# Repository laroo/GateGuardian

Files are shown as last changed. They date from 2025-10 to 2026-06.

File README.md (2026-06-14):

# Gate Guardian



  

**Automating the Sommer Twist 350 Swing Gate with ESP32 and MQTT**

This repository contains the design and code for Gate Guardian, an ESP32 swing gate controller designed to operate and monitor a Sommer Twist 350 swing gate. The system integrates remote control via MQTT over Ethernet, real-time status monitoring, and visual feedback. The design emphasizes reliability, safety, and ease of installation.

## Changelog

v1.1
- Changed pins for status LEDs as these were input only:
  - Red LED: GPIO 17 (from GPIO 39)
  - Green LED: GPIO 5 (from GPIO 36)
  - Photo eye: GPIO 36 (from GPIO 5)

v1.0
- Initial release

## MQTT Configuration

### MQTT Topics

```
gateguardian/state = CLOSED
gateguardian/sensor/lock = 0
gateguardian/sensor/lights = 0
gateguardian/sensor/photo_eye = 0
gateguardian/sensor/external_relay = 0
gateguardian/client_id = esp32_gate_FFAA00
gateguardian/uptime = 1510
gateguardian/in_motion = 0
```

### MQTT Commands

```
gateguardian/command = OPEN
gateguardian/command = CLOSE
gateguardian/command = STOP
```

## Home Assistant Configuration

The Home Assistant configuration can be found [here](home-assistant/configuration.yaml).

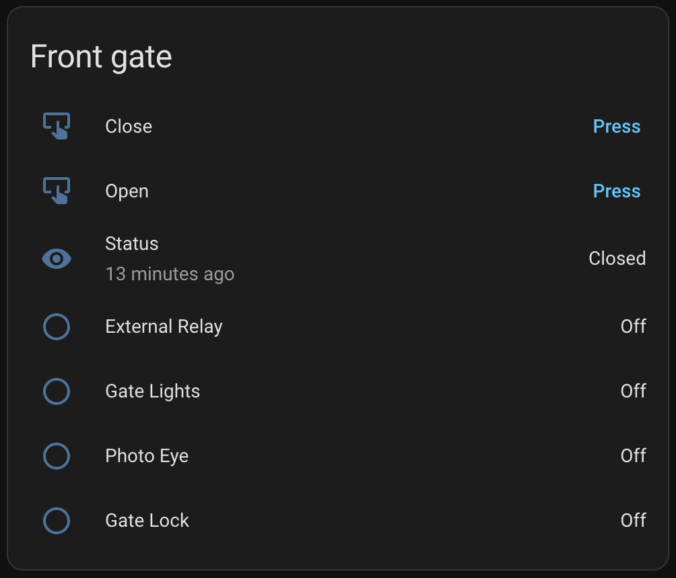
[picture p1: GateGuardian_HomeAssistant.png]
GateGuardian_HomeAssistant


## Schematics and PCB

Used LibrePCB to design the schematics and PCB.

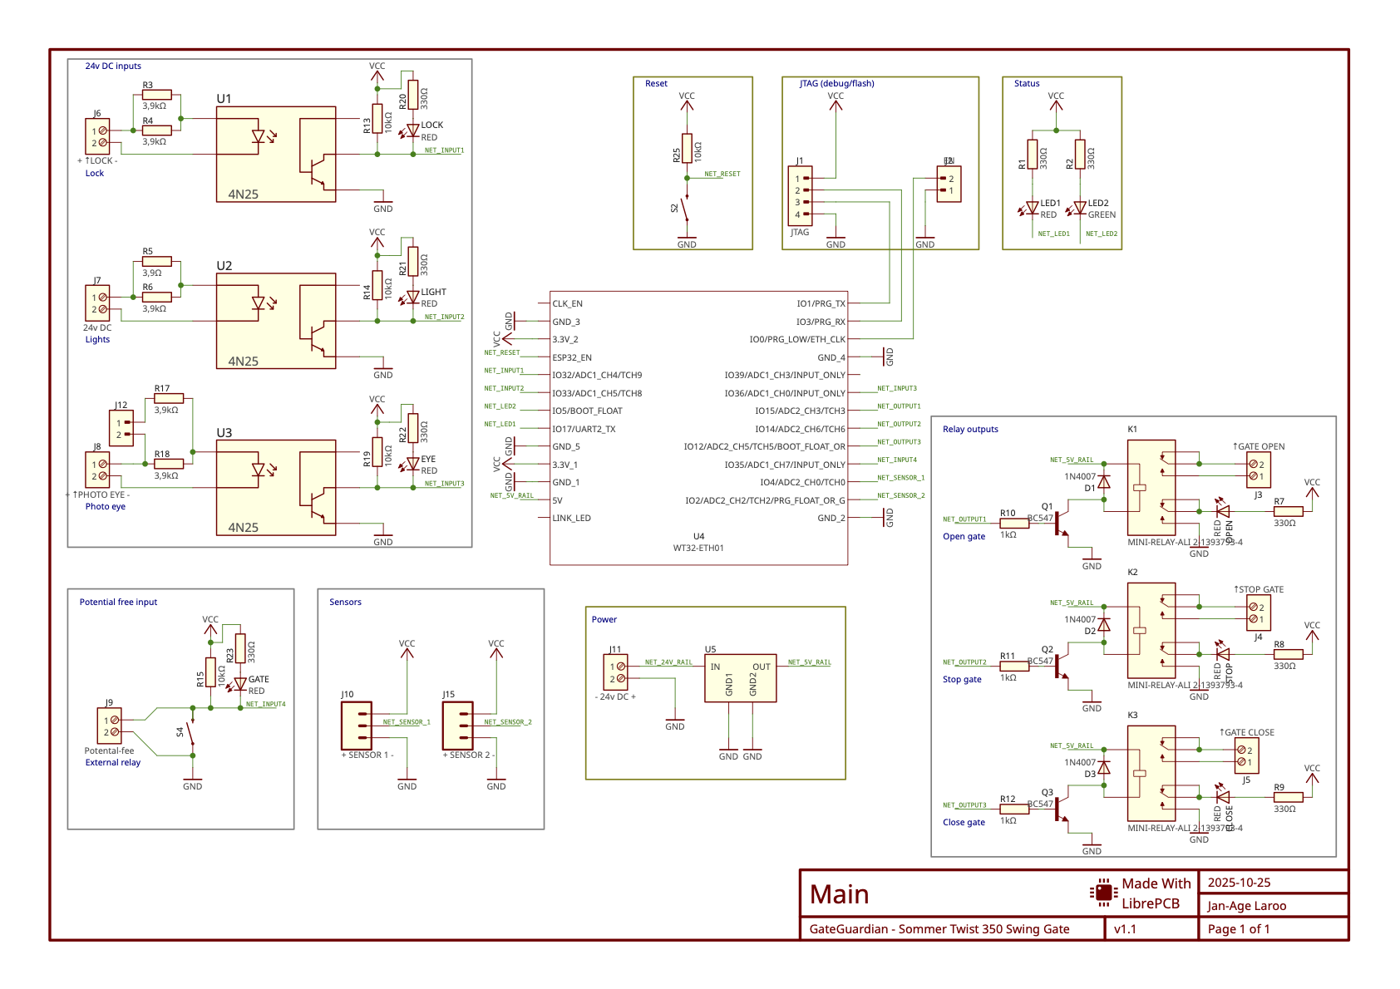
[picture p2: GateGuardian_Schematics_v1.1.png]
Schematic


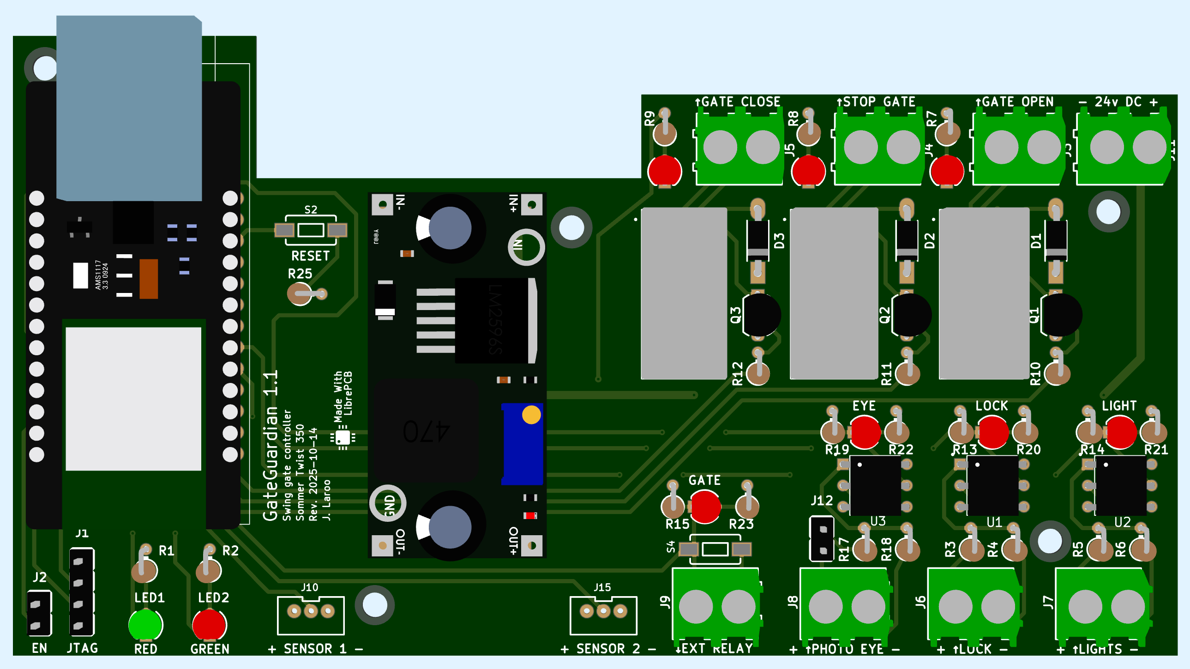
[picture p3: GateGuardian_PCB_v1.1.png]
PCB


Gerber files for the PCB can be found [here](librepcb/output/v1.1/gerber).

# Input/Output

| Pin | Direction | Function | Note |
|----|---|---|---|
| GPIO 12 | Output | Gate Close Relay | Pulse to close the gate |
| GPIO 14 | Output | Gate Stop Relay | Pulse to stop the gate |
| GPIO 15 | Output | Gate Open Relay | Pulse to open the gate |
| GPIO 17 | Output | Red LED | Blinking during closing, solid during opening |
| GPIO 5 | Output | Green LED | Blinking during opening, solid during closing |
| GPIO 33 | Input | Gate Lights | Blinking warning light when opening or cloing |
| GPIO 32 | Input | Gate Lock | Enabled when gate is closed |
| GPIO 35 | Input | External Relay | Triggered when gate is closed |
| GPIO 36 | Input | Photo eye | When someone/omething goes through the gate |
| GPIO 4 | Input | Sensor 1 | Optional sensor (dht22 temperature sensor) |
| GPIO 2 | Input | Sensor 2 | Optional sensor (not used) |

## Code

The firmware is built on the Arduino framework using PlatformIO and implements a robust gate control system with the following key features:

- **MQTT Integration**: Remote control and status monitoring via MQTT over Ethernet (W5500)
- **Visual Feedback**: Dual LED system (red/green) indicating gate state with blinking patterns during movement
- **Position Sensing**: Real-time gate position detection using magnetic sensors
- **Safety Features**: Relay pulse timing, state machine logic, and operation timeouts
- **Diagnostics**: Serial output at 115200 baud for debugging and monitoring

### Platform IO Setup

```
pyenv local 3.13
python -m venv .venv
source .venv/bin/activate
pip install -r requirements.txt
```

### Build

```
pio run
```

### Test

```
pio test -v -e native
```

Run a single test:

```
TEST_FILTER=test_open_cycle pio test -v -e native
```

### Upload (Serial)

```
pio run --target upload -v
```

### OTA (Over-the-Air) Update

The firmware includes [ElegantOTA](https://github.com/ayushsharma82/ElegantOTA) for wireless firmware updates over the network.

1. Open a browser and navigate to `http://<device-ip>/update`
2. Authenticate with the configured `OTA_USERNAME` and `OTA_PASSWORD`
3. Select the firmware binary (`.pio/build/esp32/firmware.bin`) and upload

OTA credentials are set as compile-time build flags in `private_config.ini`:

```ini
'-D OTA_USERNAME=youruser'
'-D OTA_PASSWORD=yourpassword'
```

### Web Interface

The device runs an HTTP server on port 80 with the following endpoints:

| Endpoint | Description |
|---|---|
| `/` | Device identification |
| `/gate/open` | Command gate to open |
| `/gate/close` | Command gate to close |
| `/gate/stop` | Command gate to stop |
| `/update` | ElegantOTA firmware update page |

### MQTT Sequence Recording

To capture live gate behaviour as a test sequence, enable recording in `private_config.ini`:

```ini
-D MQTT_SEQUENCE_RECORD
```

Then subscribe to the recording topic:

```sh
mosquitto_sub -h <broker> -p <port> -u <username> -P <password> -t gateguardian/sequence
```

Each received line is a CSV row ready to paste into a new `test/sequences/*.csv` file. Prepend the header:

```
timestamp_ms,sensorLock,sensorLights,sensorPhotoEye,sensorExternalRelay,expectedState
```

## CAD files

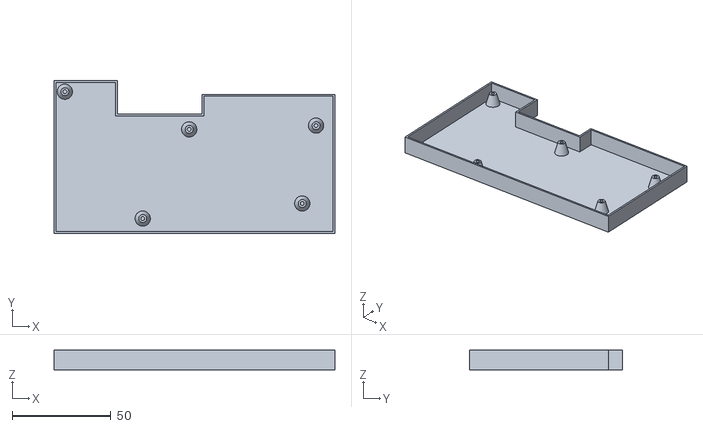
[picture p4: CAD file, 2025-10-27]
enclosure/gateguardian_box.stl
142.1 x 77.2 x 10.0

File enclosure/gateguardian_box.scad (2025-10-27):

// Import and extrude the GateGuardian box SVG
// Creates a 1mm thick wall with 10mm height and 0.5mm floor

$fn = 100;

// Define drill hole parameters
drill_radius = 4;
top_radius = 2;
drill_height = 7;
svg_height = 77209.998;
cutout_diameter = 2;
cutout_depth = 5;
box_height = 10;

// Define drill hole positions
drill_positions = [
    [(5799.4961 - 300) / 1000, (svg_height - (5880.9316 - 300)) / 1000],
    [(45168.711 - 300) / 1000, (svg_height - (70018.875 - 300)) / 1000],
    [(68659.102 - 300) / 1000, (svg_height - (24936.012 - 300)) / 1000],
    [(132804.52 - 300) / 1000, (svg_height - (23039.188 - 300)) / 1000],
    [(125817.86 - 300) / 1000, (svg_height - (62406.035 - 300)) / 1000]
];

difference() {
    union() {
        // Floor - 0.5mm thick
        linear_extrude(height = 0.5) {
            import("GateGuardian_box_only.svg");
        }
        
        // Walls - 1mm thick, 10mm height (starting from floor top)
        translate([0, 0, 0.5])
            linear_extrude(height = 9.5) {
                difference() {
                    import("GateGuardian_box_only.svg");
                    offset(delta = -1) {
                        import("GateGuardian_box_only.svg");
                    }
                }
            }
        
        // Drill holes - 5 conical cylinders
        translate([0, -0.6, 0]) {
            for (pos = drill_positions) {
                translate([pos[0], pos[1], 0])
                    cylinder(h = drill_height, r1 = drill_radius, r2 = top_radius);
            }
        }
    }
    
    // Cut out 2mm diameter cylinders, 5mm deep from the top
    translate([0, -0.6, 0]) {
        for (pos = drill_positions) {
            translate([pos[0], pos[1], box_height - cutout_depth])
                cylinder(h = cutout_depth + 0.1, r = cutout_diameter / 2);
        }
    }
}

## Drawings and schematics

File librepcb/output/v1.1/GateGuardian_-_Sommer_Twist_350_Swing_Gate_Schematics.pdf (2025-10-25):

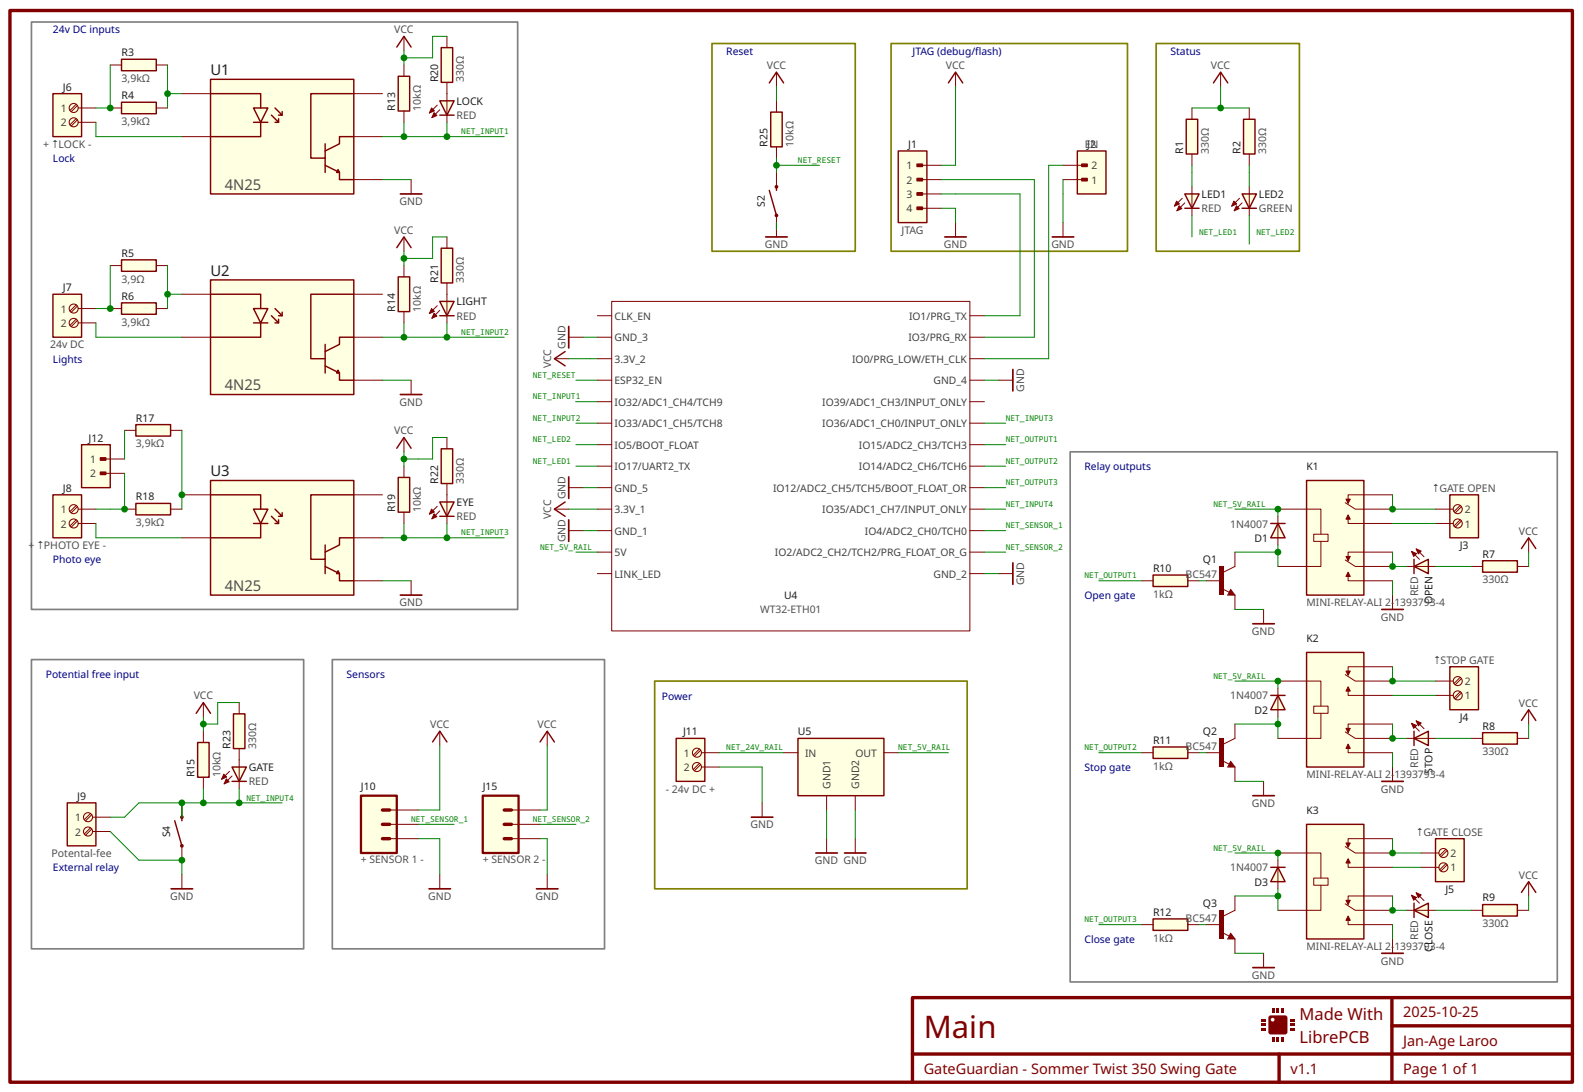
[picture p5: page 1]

GateGuardian - Sommer Twist 350 Swing Gate

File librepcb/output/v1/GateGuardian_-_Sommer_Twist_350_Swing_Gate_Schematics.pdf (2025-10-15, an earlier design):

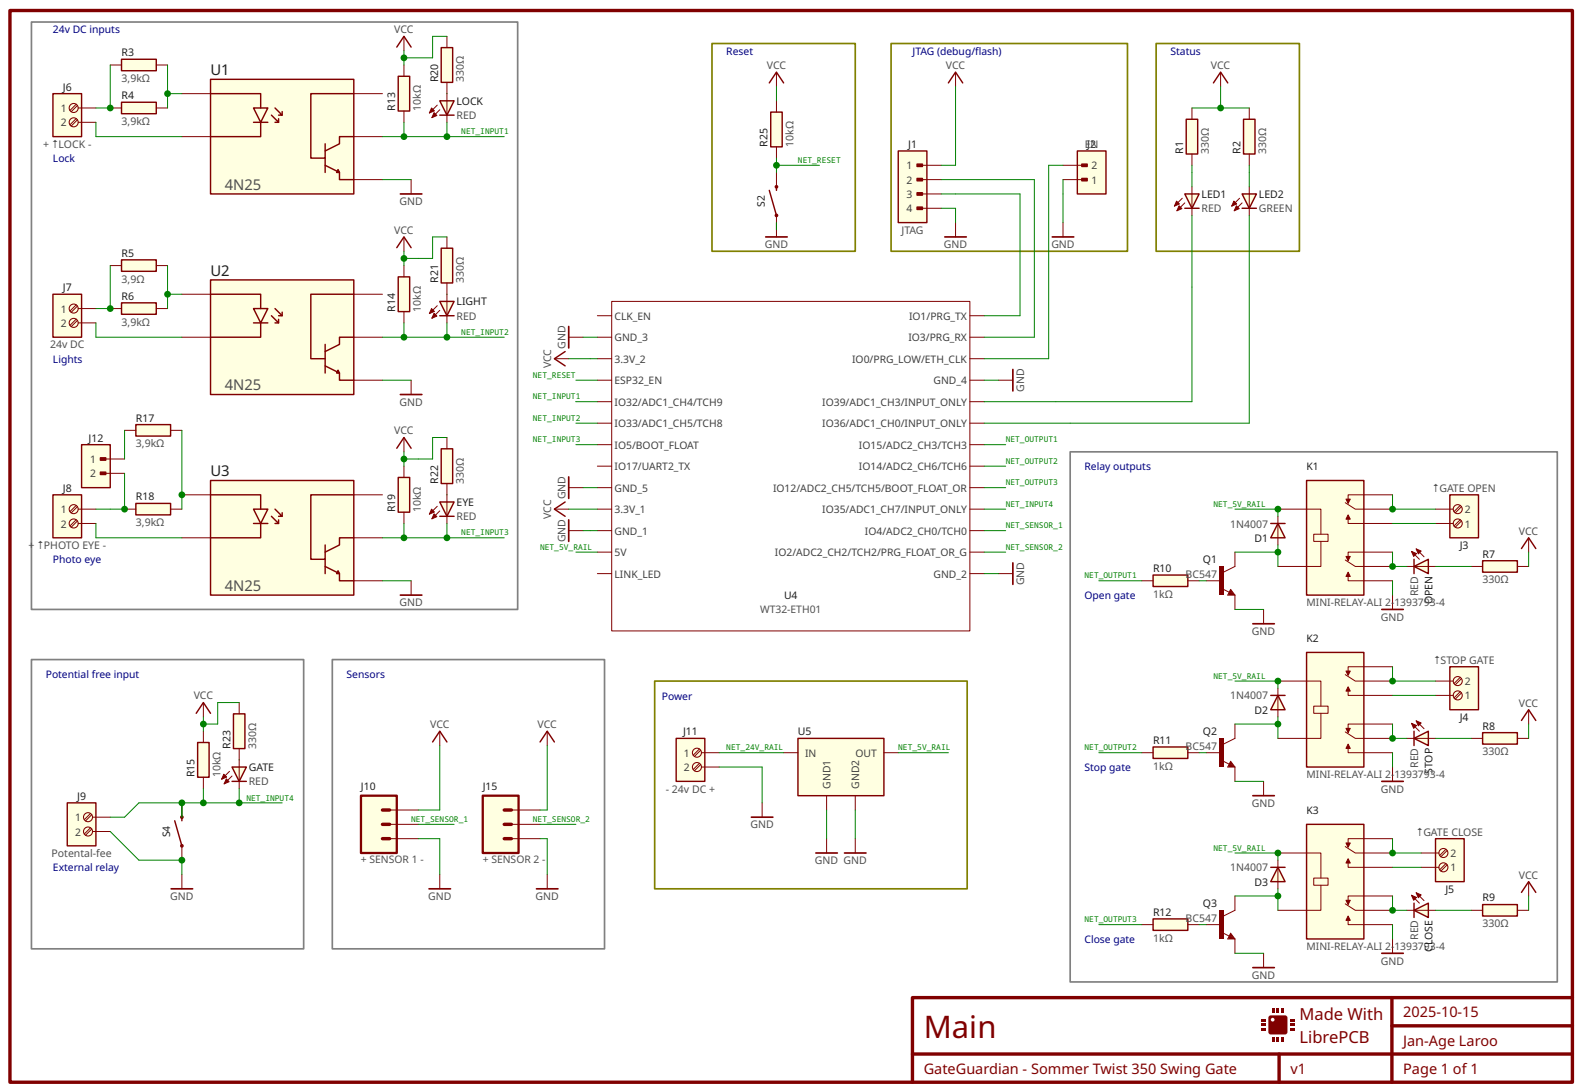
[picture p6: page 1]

GateGuardian - Sommer Twist 350 Swing Gate

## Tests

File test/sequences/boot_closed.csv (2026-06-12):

# boot_closed.csv
# Gate is closed at boot: lock sensor HIGH | external relay LOW.
# _handleBootupState() sees sensorLockGate=true → CLOSED immediately.
# timestamp_ms | sensorLock | sensorLights | sensorPhotoEye | sensorExternalRelay | expectedState
0 | 1 | 0 | 0 | 0 | CLOSED
100 | 1 | 0 | 0 | 0 | CLOSED

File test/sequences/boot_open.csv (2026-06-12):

# boot_open.csv
# Gate sensor LOW at boot: lock=0 | external relay=1 → UNKNOWN | wait 20s → OPEN.
# _handleBootupState() sees sensorLockGate=false → UNKNOWN.
# After 20000ms the state machine (GATE_UNKNOWN branch) sees sensorExternalRelay=1 → OPEN.
# timestamp_ms | sensorLock | sensorLights | sensorPhotoEye | sensorExternalRelay | expectedState
0 | 0 | 0 | 0 | 1 | UNKNOWN
100 | 0 | 0 | 0 | 1
10000 | 0 | 0 | 0 | 1
20100 | 0 | 0 | 0 | 1 | OPEN

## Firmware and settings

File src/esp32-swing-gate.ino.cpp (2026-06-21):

/**
 * ESP32 Swing Gate Controller
 * Main sketch file for controlling Sommer Twist 350 swing gate
 *
 * Features:
 * - Manual control via button
 * - MQTT remote control via Ethernet
 * - LED status indicators
 * - Gate position sensing
 * - Serial diagnostics at 115200 baud
 */

#include "Arduino.h"
#include <PubSubClient.h>
#include <arduino-timer.h>
#include <EthernetESP32.h>
// #include <WiFi.h>
#include <WebServer.h>
#include <ElegantOTA.h>
#include "webmanager.h"
#include "DHT.h"
// #include "RemoteDebug.h"


// #include <PubSubClient.h>

#include "config.h"

#include "esp_system.h"
#include "esp32-hal-gpio.h"
#include "gate.h"
#include "ledmanager.h"
#include "mqttmanager.h"
#include <SPI.h>
#include <Network.h>

EMACDriver driver(ETH_PHY_LAN8720, 23, 18, 16);   // note powerPin = 16 required
// EMACDriver driver(ETH_PHY_LAN8720, ETH_PHY_MDC, ETH_PHY_MDIO, ETH_PHY_POWER);
// EthernetClient   ethClient;

EthernetClient ethClient;
WiFiClient wifiClient;

// Pointer to the active client (Ethernet or WiFi)
NetworkClient* activeClient = nullptr;

// Connection check result (used by network event handler)
int connectionStatus = 0;

// DHTesp dhtSensor;
// config.sensor1Pin, DHTesp::DHT22

// #define DHTPIN 4
// #define DHTTYPE DHT22
// DHT dhtSensor(DHTPIN, DHTTYPE);

// RemoteDebug Debug;


// ============================================================================
// NETWORK EVENT HANDLER
// ============================================================================
// WARNING: This function is called from a separate FreeRTOS task (thread)!
void onNetworkEvent(arduino_event_id_t event, arduino_event_info_t info) {
  Serial.printf("[Network-event] event: %d\n", event);

  switch (event) {
    case ARDUINO_EVENT_ETH_START:
      Serial.println("[ETH] Ethernet started");
      break;
    case ARDUINO_EVENT_ETH_STOP:
      Serial.println("[ETH] Ethernet stopped");
      break;
    case ARDUINO_EVENT_ETH_CONNECTED:
      Serial.println("[ETH] Ethernet connected - Link UP");
      break;
    case ARDUINO_EVENT_ETH_DISCONNECTED:
      Serial.println("[ETH] Ethernet disconnected - Link DOWN");
      connectionStatus = 0;
      activeClient = nullptr;
      break;
    case ARDUINO_EVENT_ETH_GOT_IP:
      Serial.print("[ETH] Obtained IP address: ");
      Serial.println(IPAddress(info.got_ip.ip_info.ip.addr));
      Serial.print("[ETH] Gateway: ");
      Serial.println(IPAddress(info.got_ip.ip_info.gw.addr));
      Serial.print("[ETH] Netmask: ");
      Serial.println(IPAddress(info.got_ip.ip_info.netmask.addr));
      connectionStatus = 1;
      activeClient = &ethClient;
      break;
    case ARDUINO_EVENT_ETH_GOT_IP6:
      Serial.println("[ETH] Ethernet IPv6 is preferred");
      break;
    case ARDUINO_EVENT_WIFI_STA_START:
      Serial.println("[WiFi] WiFi client started");
      break;
    case ARDUINO_EVENT_WIFI_STA_STOP:
      Serial.println("[WiFi] WiFi client stopped");
      break;
    case ARDUINO_EVENT_WIFI_STA_CONNECTED:
      Serial.println("[WiFi] Connected to access point");
      break;
    case ARDUINO_EVENT_WIFI_STA_DISCONNECTED:
      Serial.println("[WiFi] Disconnected from WiFi access point");
      if (connectionStatus == 2) {
        connectionStatus = 0;
        activeClient = nullptr;
      }
      break;
    case ARDUINO_EVENT_WIFI_STA_GOT_IP:
      Serial.print("[WiFi] Obtained IP address: ");
      Serial.println(IPAddress(info.got_ip.ip_info.ip.addr));
      connectionStatus = 2;
      activeClient = &wifiClient;
      break;
    case ARDUINO_EVENT_WIFI_STA_LOST_IP:
      Serial.println("[WiFi] Lost IP address");
      if (connectionStatus == 2) {
        connectionStatus = 0;
        activeClient = nullptr;
      }
      break;
    default:
      break;
  }
}

// ============================================================================
// CONFIGURATION STRUCTURE
// ============================================================================
struct Config {
  char clientId[32]; // Random client ID generated at startup

  // Timing Settings
  unsigned long gateOperationTime = 20000; // 20 seconds (Requirement 2)
  unsigned long relayPulseTime = 500;      // 500ms (Requirement 1)
  unsigned long publishInterval = 10000;   // 10 seconds (Requirement 7)
  unsigned long blinkInterval = 500;       // 500ms (Requirement 3)
  unsigned long debounceTime = 50;         // 50ms button debounce

  // GPIO Pins
  int redLedPin = 17;
  int greenLedPin = 5;

  int gateLightsPin = 33;
  int gateLockPin = 32;
  int externalRelayPin = 35;  // Input only
  int photoEyePin = 36;  // Input only

  int sensor1Pin = 4;
  int sensor2Pin = 2;

  int openRelayPin = 15;
  int closeRelayPin = 12;
  int stopRelayPin = 14;

};

// ============================================================================
// GLOBAL VARIABLES
// ============================================================================
Config config;
Gate *gate = nullptr;
LEDManager *ledManager = nullptr;
MQTTManager *mqttManager = nullptr;

// Timer for main loop management
auto mainTimer = timer_create_default();

// Previous gate state for change detection
GateState previousGateState = GATE_UNKNOWN;

// Button handling variables
bool lastButtonState = LOW; // Button is active LOW with pull-up
bool currentButtonState = HIGH;
unsigned long lastButtonChange = 0;
bool buttonPressed = false; // Flag to track button press events

// ============================================================================
// FUNCTION DECLARATIONS
// ============================================================================
void initializeGPIO();
void handleBootDelay();
// void handleButtonInput();
void printConfigSummary();
int checkConnection();
bool checkConnectionCallback(void *);
bool reportConnectionStatusCallback(void *);
// bool checkInputCallback(void *);
NetworkClient* getActiveClient();


// ============================================================================
// SETUP FUNCTION
// ============================================================================
void setup() {

  // Boot delay for power outage safety (Requirement 8)
  handleBootDelay();

  // Initialize GPIO pins (Requirement 5.1)
  initializeGPIO();

  // Initialize serial communication at 115200 baud (Requirement 4.1)
  Serial.begin(115200);
  delay(100); // Allow serial to initialize

  // Print initialization messages (Requirement 4.1)
  Serial.println("[INIT] ESP32 Gate Controller v1.0 starting...");
  Serial.print("[INIT] Free heap: ");
  Serial.print(ESP.getFreeHeap());
  Serial.println(" bytes");
  
  // dhtSensor.begin();
  // float temperature = dhtSensor.readTemperature();
  // float humidity = dhtSensor.readHumidity();
  // Serial.println("Temp:     " + String(temperature, 2) + "°C");
  // Serial.println("Humidity: " + String(humidity, 1) + "%");

  // Generate random client ID for MQTT
  randomSeed(analogRead(0));
  sprintf(config.clientId, "esp32_gate_%06X", random(0xFFFFFF));
  Serial.print("[INIT] MQTT Client ID: ");
  Serial.println(config.clientId);

  // Debug.begin(config.clientId);    // Initialize the WiFi server
  // Debug.setResetCmdEnabled(true);  // Enable the reset command
  // Debug.showProfiler(false);        // Profiler (Good to measure times, to optimize codes)
  // Debug.showColors(true);          // Colors
  // Serial.println("[RemoteDebug] Initialized");
  
  // Initialize Gate controller
  gate = new Gate();
  if (gate) {
    gate->initialize();
    Serial.println("[INIT] Gate controller created and initialized");
  } else {
    Serial.println("[ERROR] Failed to create Gate controller");
  }

  // Initialize LED Manager
  ledManager = new LEDManager(config.redLedPin, config.greenLedPin);
  if (ledManager) {
    ledManager->initialize();

    // Set initial LED state based on gate state
    if (gate) {
      GateState initialState = gate->getState();
      ledManager->setStatus(initialState);
      previousGateState = initialState;
    }

    Serial.println("[INIT] LED manager initialized");
  } else {
    Serial.println("[ERROR] Failed to initialize LED manager");
  }

  // Register network event listener
  Network.onEvent(onNetworkEvent);
  Serial.println("[INIT] Network event listener registered");

  Ethernet.init(driver);

  Serial.print("Link 1: ");
  Serial.println(Ethernet.linkStatus()); //Prints 2 = LinkOFF, as expected


  Serial.println("Initialize Ethernet with DHCP:");
  if (Ethernet.begin()) {
    Serial.print("  DHCP assigned IP ");
    Serial.println(Ethernet.localIP());
  } else {
    Serial.println("Failed to configure Ethernet using DHCP");
    // while (true) {
    //   delay(1);
    // }
  }

  Serial.print("Link 2: ");
  Serial.println(Ethernet.linkStatus()); //prints 1 = LinkON, even with no cable plugged in

  // Check for Ethernet hardware present
  if (Ethernet.hardwareStatus() == EthernetNoHardware) {
    Serial.println("Ethernet shield was not found.  Sorry, can't run without hardware. :(");
    // while (true) {
    //   delay(1); // do nothing, no point running without Ethernet hardware
    // }
  }
  if (Ethernet.linkStatus() == LinkOFF) {
    //This statement should print but doesn't when I test with no cable
    Serial.println("Ethernet cable is not connected.");
  }

  // if (MDNS.begin("gateguardian")) {
  //   Serial.println("MDNS responder started");
  // }

  // Initialize MQTT Manager (Requirements 7.1, 7.2)
  mqttManager = new MQTTManager(MQTT_BROKER, MQTT_PORT, 
                                config.clientId, MQTT_TOPIC_STATUS, 
                                MQTT_TOPIC_COMMAND, MQTT_USERNAME, MQTT_PASSWORD);
  if (mqttManager) {
    mqttManager->initialize(activeClient);
    
    // Set gate controller reference for command handling
    if (gate) {
      mqttManager->setGateController(gate);
    }
    
    Serial.println("[INIT] MQTT manager initialized");
  } else {
    Serial.println("[ERROR] Failed to initialize MQTT manager");
  }

  Serial.println("[INIT] Setting up web server...");
  setupWebServer(config.clientId);

  // Print configuration summary
  printConfigSummary();

  // Schedule checkConnection to run every 1000ms (1 second)
  mainTimer.every(5000, checkConnectionCallback);
  Serial.println("[INIT] Connection check scheduled every 1 second");

  // Schedule input to run every 1000ms
  // mainTimer.every(10000, checkInputCallback);
  // Serial.println("[INIT] input check scheduled every 1 second");


  // Schedule connection status reporting every 2000ms (2 seconds)
  mainTimer.every(5000, reportConnectionStatusCallback);
  Serial.println("[INIT] Connection status reporting scheduled every 2 seconds");

  Serial.println("[INIT] System initialization complete");
  Serial.println("======================================");
}

// Timer callback for connection checking
bool checkConnectionCallback(void *) {
  connectionStatus = checkConnection();
  return true; // Repeat the timer
}

// Timer callback for reporting connection status
bool reportConnectionStatusCallback(void *) {
  if (connectionStatus == 1) {
    Serial.println("Connected to Ethernet");
  }
  else if (connectionStatus == 2) {
    Serial.println("Connected to Wi-Fi");
  }
  else {
    Serial.println("Not Connected");
  }
  return true; // Repeat the timer
}

int checkConnection() {
  // Check if Ethernet is available
  if(ethClient.connected() && (Ethernet.linkStatus() == LinkON)) {
    Serial.println("Existing Ethernet connection");
    activeClient = &ethClient;
    return 1;
  }
  else if (Ethernet.linkStatus() == LinkON) {
    // Use Ethernet connection
    Serial.println("Ethernet LINKON");
    if (!ethClient.connected()) {
      Serial.println("Connecting via Ethernet...");
        // beginMicros = micros();
        WiFi.disconnect();
        //delay(5000);
        activeClient = &ethClient;
        return 1;
    }
  }
  // else{
  //   Serial.println("Not Successfull Ethernet Connection");
  // }

 if (WiFi.status() == WL_CONNECTED) {
    Serial.println("Existing Wi-Fi connection");
    activeClient = &wifiClient;
    return 2;
  }

  // Use Wi-Fi connection
  WiFi.begin("Wokwi-GUEST", "", 6);
  Serial.println("Connecting via Wi-Fi...");
  for (int i = 0; i < 50; i++) {
    if ((WiFi.status() == WL_CONNECTED))
      Serial.println(" CONNECTED");
      break;
    delay(100);
    Serial.print(".");
  }

  if (WiFi.status() == WL_CONNECTED) {
    Serial.println("Connected to Wi-Fi ");
    // Serial.println(WiFi.localIP());
    // Additional Wi-Fi initialization if needed
    activeClient = &wifiClient;
    return 2;
  }
  else{
    Serial.println("Wi-Fi not Connected");
  }

  activeClient = nullptr;
  return 0;
}

// ============================================================================
// MAIN LOOP
// ============================================================================
void loop() {

    static unsigned long lastUpdate = 0;

    // Update button state every 1ms
    if (millis() - lastUpdate >= 1) {
        lastUpdate = millis();
        // gateLightsButton.update();
        // gateLockButton.update();
        // externalRelayButton.update();
        // photoEyeButton.update();    
    }



  // Connection status is now reported by timer callback every 2 seconds
  if (activeClient && connectionStatus > 0) {

    // static unsigned long lastNetworkUpdate = 0;
    // if (millis() - lastNetworkUpdate >= 500) {
    //     lastNetworkUpdate = millis(); 
    //     Serial.println("Active Network Loop!");
    // }

    loopWebServer();

    // Update MQTT manager (Requirements 7.1, 7.2, 7.3, 7.4)
    if (mqttManager) {
      mqttManager->setClient(activeClient);
      mqttManager->update();
    }
    // Debug.handle();

  }

  unsigned long loopStart = millis();

  // Handle button input with debouncing
  // handleButtonInput();

  // Update gate controller
  if (gate) {
    gate->update();

    // Check for gate state changes and update LEDs
    GateState currentState = gate->getState();
    if (currentState != previousGateState) {
      if (ledManager) {
        ledManager->setStatus(currentState);
      }
      previousGateState = currentState;
    }
  }

  // Update LED manager
  if (ledManager) {
    ledManager->update();
  }

  // Tick main timer for any scheduled tasks
  mainTimer.tick();

  // Calculate loop execution time
  unsigned long loopTime = millis() - loopStart;

  // Ensure loop completes within 1 second (Requirement 5.2)
  if (loopTime > 1000) {
    Serial.print("[WARNING] Loop execution time exceeded 1 second: ");
    Serial.print(loopTime);
    Serial.println("ms");
  }

  // Small delay to prevent excessive CPU usage
  delay(10);
}

// ============================================================================
// BOOT DELAY (Requirement 8)
// ============================================================================
void handleBootDelay() {
  // Only run boot delay on power-on reset, not after software reset
  esp_reset_reason_t reason = esp_reset_reason();
  if (reason == ESP_RST_SW) {
    // This is the clean reboot after boot delay — skip
    Serial.begin(115200);
    delay(100);
    Serial.println("[BOOT] Software reset detected, skipping boot delay");
    return;
  }

  // Force relay pins LOW immediately to prevent spurious signals
  pinMode(config.openRelayPin, OUTPUT);
  pinMode(config.closeRelayPin, OUTPUT);
  pinMode(config.stopRelayPin, OUTPUT);
  digitalWrite(config.openRelayPin, LOW);
  digitalWrite(config.closeRelayPin, LOW);
  digitalWrite(config.stopRelayPin, LOW);

  // Initialize LEDs for boot delay indication
  pinMode(config.redLedPin, OUTPUT);
  pinMode(config.greenLedPin, OUTPUT);

  Serial.begin(115200);
  delay(100);
  Serial.println("[BOOT] Power-on detected, starting boot delay...");
  Serial.print("[BOOT] Waiting ");
  Serial.print(BOOT_DELAY_MS / 1000);
  Serial.println(" seconds for Sommer Twist 350 to initialize");

  unsigned long startTime = millis();
  unsigned long remaining = BOOT_DELAY_MS;
  int lastSecond = -1;
  bool ledState = false;

  while (remaining > 0) {
    unsigned long elapsed = millis() - startTime;
    remaining = (elapsed >= BOOT_DELAY_MS) ? 0 : (BOOT_DELAY_MS - elapsed);
    int currentSecond = remaining / 1000;

    // Print countdown once per second
    if (currentSecond != lastSecond) {
      lastSecond = currentSecond;
      Serial.print("[BOOT] Countdown: ");
      Serial.print(currentSecond + 1);
      Serial.println("s remaining");
    }

    // Blink both LEDs together (250ms on/off) as boot-delay indicator
    ledState = (millis() / 250) % 2 == 0;
    digitalWrite(config.redLedPin, ledState ? HIGH : LOW);
    digitalWrite(config.greenLedPin, ledState ? HIGH : LOW);

    // Keep relay pins forced LOW during delay
    digitalWrite(config.openRelayPin, LOW);
    digitalWrite(config.closeRelayPin, LOW);
    digitalWrite(config.stopRelayPin, LOW);

    delay(10);
  }

  // Turn LEDs off before restart
  digitalWrite(config.redLedPin, LOW);
  digitalWrite(config.greenLedPin, LOW);

  Serial.println("[BOOT] Boot delay complete, performing software reset...");
  Serial.flush();
  delay(100);
  ESP.restart();
}

// ============================================================================
// GPIO INITIALIZATION
// ============================================================================
void initializeGPIO() {

  // Configure LED outputs
  pinMode(config.redLedPin, OUTPUT);
  pinMode(config.greenLedPin, OUTPUT);
  digitalWrite(config.redLedPin, LOW);
  digitalWrite(config.greenLedPin, LOW);

  // Configure relay outputs
  pinMode(config.openRelayPin, OUTPUT);
  pinMode(config.closeRelayPin, OUTPUT);
  pinMode(config.stopRelayPin, OUTPUT);
  digitalWrite(config.openRelayPin, LOW);
  digitalWrite(config.closeRelayPin, LOW);
  digitalWrite(config.stopRelayPin, LOW);
  
  // Configure sensor input with internal pull-up  
  pinMode(config.gateLightsPin, INPUT_PULLUP);
  pinMode(config.gateLockPin, INPUT_PULLUP);
  pinMode(config.externalRelayPin, INPUT);
  pinMode(config.photoEyePin, INPUT);

  // Configure sensor input with internal pull-up
  pinMode(config.sensor1Pin, INPUT);
  pinMode(config.sensor2Pin, INPUT);
  
}

// ============================================================================
// CONFIGURATION SUMMARY
// ============================================================================
void printConfigSummary() {
  Serial.println("[CONFIG] System Configuration:");
  Serial.print("  Gate Operation Time: ");
  Serial.print(config.gateOperationTime);
  Serial.println("ms");
  Serial.print("  Relay Pulse Time: ");
  Serial.print(config.relayPulseTime);
  Serial.println("ms");
  Serial.print("  Publish Interval: ");
  Serial.print(config.publishInterval);
  Serial.println("ms");
}

// ============================================================================
// GET ACTIVE CLIENT
// ============================================================================
/**
 * Returns a pointer to the active network client (Ethernet or WiFi)
 * based on the current connection status.
 * 
 * @return NetworkClient* Pointer to active client, or nullptr if no connection
 */
NetworkClient* getActiveClient() {
  return activeClient;
}

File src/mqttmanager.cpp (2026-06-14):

/**
 * MQTTManager.cpp - ESP32 Swing Gate Controller MQTT Manager Implementation
 *
 * Implementation of MQTT communication over Ethernet for remote gate control
 * and status reporting using W5500 Ethernet shield and PubSubClient library.
 */

#include "Arduino.h"
#include "mqttmanager.h"
#include <ETH.h>

// Static instance pointer for callback handling
MQTTManager* MQTTManager::_instance = nullptr;

// ============================================================================
// MQTT MANAGER CLASS IMPLEMENTATION
// ============================================================================

MQTTManager::MQTTManager(const char* broker, int port, const char* clientId,
                         const char* statusTopic, const char* commandTopic,
                         const char* username, const char* password)
    : _port(port), _ethClient(nullptr), _mqttClient(nullptr),
      _initialized(false), _wifiConnected(false), _autoPublishEnabled(true),
      _lastPublish(0), _lastConnectionAttempt(0), _reconnectAttempts(0),
      _gateController(nullptr), _useAuth(false) {
    
    // Copy configuration strings
    strncpy(_broker, broker, sizeof(_broker) - 1);
    _broker[sizeof(_broker) - 1] = '\0';
    
    strncpy(_clientId, clientId, sizeof(_clientId) - 1);
    _clientId[sizeof(_clientId) - 1] = '\0';
    
    strncpy(_statusTopic, statusTopic, sizeof(_statusTopic) - 1);
    _statusTopic[sizeof(_statusTopic) - 1] = '\0';
    
    strncpy(_commandTopic, commandTopic, sizeof(_commandTopic) - 1);
    _commandTopic[sizeof(_commandTopic) - 1] = '\0';
    
    // Copy authentication credentials if provided
    if (username != nullptr && password != nullptr) {
        strncpy(_username, username, sizeof(_username) - 1);
        _username[sizeof(_username) - 1] = '\0';
        
        strncpy(_password, password, sizeof(_password) - 1);
        _password[sizeof(_password) - 1] = '\0';
        
        _useAuth = true;
        Serial.println("[MQTT] Authentication enabled");
    } else {
        _username[0] = '\0';
        _password[0] = '\0';
        Serial.println("[MQTT] Authentication disabled");
    }
    
    // Set static instance for callback handling
    _instance = this;
    
    Serial.println("[MQTT] MQTTManager constructor called");
}

MQTTManager::~MQTTManager() {
    Serial.println("[MQTT] MQTTManager destructor called");
    
    if (_mqttClient) {
        _mqttClient->disconnect();
        delete _mqttClient;
    }
    
    if (_ethClient) {
        delete _ethClient;
    }
    
    _instance = nullptr;
}

void MQTTManager::initialize(NetworkClient* activeClient) {
    Serial.println("[MQTT] Initializing MQTT manager...");
    
    // Initialize WiFi connection
    // if (!_initializeWiFi()) {
    //     Serial.println("[ERROR] Failed to initialize WiFi connection");
    //     return;
    // }
    
    // Create MQTT client
    _ethClient = activeClient;
    
    // if (!_ethClient) {
    //     Serial.println("[ERROR] Failed to create ethernet client");
    //     return;
    // }
    
    _mqttClient = new PubSubClient;
    if (!_mqttClient) {
        Serial.println("[ERROR] Failed to create MQTT client");
        return;
    }
    
    // Configure MQTT client
    _mqttClient->setServer(_broker, _port);
    _mqttClient->setCallback(_messageCallback);
    
    _initialized = true;
    
    Serial.print("[MQTT] MQTT manager initialized - Broker: ");
    Serial.print(_broker);
    Serial.print(":");
    Serial.println(_port);
    Serial.print("[MQTT] Client ID: ");
    Serial.println(_clientId);
    Serial.print("[MQTT] Status topic: ");
    Serial.println(_statusTopic);
    Serial.print("[MQTT] Command topic: ");
    Serial.println(_commandTopic);
    
    // Attempt initial connection
    // connect();
}

void MQTTManager::update() {
    static unsigned long lastNetworkUpdate = 0;
    bool debug = false;
    // if (millis() - lastNetworkUpdate >= 500) {
    //     lastNetworkUpdate = millis(); 
    //     debug = true;
    // }

    
    if (!_initialized) {
        if (debug) Serial.println("[MQTT] Not initialized...");
        return;
    }

    if (!_ethClient) {
        if (debug) Serial.println("[MQTT] No client...");
        return;
    };

    // mqttClient.setClient(*activeClient);
    // if (!mqttClient.connected()) {
    //   mqttReconnect();
    // }
    // mqttClient.loop();
    
    // Tick timers
    _publishTimer.tick();
    _reconnectTimer.tick();

    // Update the client reference in case connection switched between Ethernet/WiFi
    if (_ethClient) {
        if (debug) Serial.println("[MQTT] Setting client...");
        _mqttClient->setClient(*_ethClient);
    }
    
    // Handle MQTT client loop
    if (_mqttClient && _mqttClient->connected()) {
        if (debug) Serial.println("[MQTT] Looping...");
        _mqttClient->loop();
    } else {
        if (debug) Serial.println("[MQTT] Not connected...");
        // Connection lost, attempt reconnection
        unsigned long currentTime = millis();
        if (currentTime - _lastConnectionAttempt >= 10000) { // Retry every 10 seconds
            Serial.println("[MQTT] Connection lost, attempting reconnection...");
            connect();
        }
    }
}
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

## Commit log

2025-10-13 Small factor board: 100x60
2025-10-14 Finished traces
2025-10-15 Final v1
    [GateGuardian_-_Sommer_Twist_350_Swing_Gate_v1_COPPER-BOTTOM.gbr, GateGuardian_-_Sommer_Twist_350_Swing_Gate_v1_COPPER-TOP.gbr, GateGuardian_-_Sommer_Twist_350_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]
2025-10-15 Invert labels esp32
2025-10-20 Move LibrePCB project to subdir; merge ESP32 code
    [GateGuardian_-_Sommer_Twist_350_Swing_Gate_v1_COPPER-BOTTOM.gbr, GateGuardian_-_Sommer_Twist_350_Swing_Gate_v1_COPPER-TOP.gbr, GateGuardian_-_Sommer_Twist_350_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]
2025-10-25 Added v1.1 schematics & PCB
    [GateGuardian_-_Sommer_Twist_350_Swing_Gate_v1.1_COPPER-BOTTOM.gbr, GateGuardian_-_Sommer_Twist_350_Swing_Gate_v1.1_COPPER-TOP.gbr, GateGuardian_-_Sommer_Twist_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]
2025-10-27 Fix stop relay; add DHT22 sensor
    [esp32-swing-gate.ino.cpp, mqttmanager.cpp]
2025-10-27 Add enclosure
    [gateguardian_box.scad]
2025-10-27 fix enclosure
    [gateguardian_box.scad, gateguardian_box.stl]
2025-11-01 Split config in esp32 and esp32_wokwi
2025-11-01 Remove DHT sensor
2025-11-01 Added gate sensor
2025-11-01 Rename sensor to gate close sensor
2025-11-01 Added other sensors to gate
2025-11-01 Publish sensors to MQTT on change
2025-11-01 Switch to external sensor instead of lock
2025-11-02 Flip external relay sensor check; added home-assistant config for MQTT
2026-06-11 Added esp32 boot delay and software reset to prevent issues during power outage
    [esp32-swing-gate.ino.cpp]
2026-06-12 Added tests for the gate class
    [boot_closed.csv, boot_open.csv, close_cycle.csv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]
2026-06-12 Added full open/close sequence from live hardware
    [full_close_cycle.csv, full_open_cycle.csv]
2026-06-12 Increase closing time from 20s to 30s
    [full_close_cycle.csv]
